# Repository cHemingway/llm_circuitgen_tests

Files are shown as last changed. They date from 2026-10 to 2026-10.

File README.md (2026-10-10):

# llm_circuitgen_tests

A benchmark of "circuit as code" tools for LLM-aided circuit design. Every tool
gets the same design brief, and each implementation lives in its own top-level
folder.

## Brief

This repository is a benchmark of various "circuit as code" tools for LLM-aided
circuit design. Each tool is given the same prompt, with the tool name and branch
substituted where needed:

> Use `<tool>` to design me a RP2354A powered Solartron 7075 multimeter
> interface, using the 50 way D connector on the Solartron. Put it in the folder
> `<tool>`. Do these changes on a new branch.
>
> DO NOT LOOK AT OTHER BRANCHES FOR CODE, RELY ON THE TOOL, THE DATASHEET, AND
> WHAT YOU CAN FIND ONLINE ONLY, DON'T COPY THE OUTPUTS OF OTHER TOOLS USED IN
> THIS BENCHMARK.
>
> In the top level folder `inputs` is a datasheet for the multimeter. It
> describes how the interface works in section 9.
>
> Signals to/from the multimeter should be opto-isolated to prevent USB ground
> noise from affecting the system. I was thinking therefore they should be done
> through shift registers to minimise the number of signals across the isolation
> barrier.
>
> Select parts from `<tool>`'s library, then LCSC where possible.
>
> Have the board sit flat on the back of the multimeter, using a vertical PCB
> mount D-Sub connector on one side and a vertical USB-B connector on the other
> side of the board.
>
> The board will be rectangular, and mechanically fixed to the solartron using
> the jackscrews on the D-Sub connector, so doesn't need any other mounting
> holes.

## Results

| Tool | Folder | Active time | of which tool time | Total tokens | API calls | API-price estimate | Schematic | PCB prints | Notes |
| --- | --- | --- | --- | --- | --- | --- | --- | --- | --- |
| [tscircuit](https://tscircuit.com) | `tscircuit/` | 3 h 11 min | 2 h 06 min | 156.3 M | 376 | $59.32 | [PDF](tscircuit/outputs/schematic.pdf) | [PDF](tscircuit/outputs/pcb-prints.pdf) | Parts from tscircuit/common, then LCSC. Session log and statistics: [`tscircuit/CONVERSATION.md`](tscircuit/CONVERSATION.md) |
| [atopile](https://atopile.io) | `atopile/` | 1 h 46 min | 38 min | 149.5 M | 370 | $49.34 | [PDF](atopile/schematic/solartron_7075_usb.pdf) | [PDF](atopile/fab/solartron_7075_usb_prints.pdf) | CLI version (`ato`, 0.15.x). This is the last open CLI line and is effectively end-of-life: [PyPI](https://pypi.org/project/atopile/) lists 0.15.9 (12 Sep 2026) as the latest release, and atopile has moved on to [0.16](https://atopile.io/enterprise). Parts from atopile's library, then LCSC. Session log and statistics: [`atopile/CONVERSATION.md`](atopile/CONVERSATION.md) |
| [SKiDL](https://github.com/devbisme/skidl) | `skidl/` | 2 h 29 min | 59 min | 124.5 M | 347 | $46.64 | [PDF](skidl/pcb/render/schematic.pdf) | [PDF](skidl/pcb/print/pcb_prints.pdf) | SKiDL 2.3.0 on KiCad 10 (the brief added "use KiCad 10"). SKiDL has no part library of its own, so parts come from KiCad's libraries, then LCSC. Board built with kinet2pcb and routed with Freerouting 2.5. SKiDL's schematic generator mis-connects nets on this design, so the schematic is drawn by a script and checked against the netlist. Statistics run to the conversation export, and exclude the merge into `main` that came after it. Session log and statistics: [`skidl/CONVERSATION.md`](skidl/CONVERSATION.md) |
| [Manta](https://github.com/Derrick-Derrickson/Manta) | `manta/` | 46 min | – | 62.9 M | 191 | – | [HTML](manta/output/solartron7075.html) | – | Manta 2.0.1 (language revision 2.0). Manta is a schematic and netlist language with no layout, so the result is a checked netlist, a KiCad netlist (with a footprint map and two generated footprints), an LCSC BOM and an HTML schematic. No PCB was made, so there are no prints. Manta's only part library is its `blinky` example; 8 part types came from it, the rest from LCSC. The session transcript kept no cost-state record, so tool time and the price estimate were not recorded; tokens and API calls are summed from the transcript's per-response usage. Statistics run to the conversation export, and exclude the merge into `main` that came after it. Notes on the tool: [`manta/README.md`](manta/README.md#notes-on-the-tool-benchmark-observations). Session log and statistics: [`manta/CONVERSATION.md`](manta/CONVERSATION.md) |

Statistics cover the Claude Code session from the first prompt to the merge into
`main`.

- **Active time:** Claude working, including tool runs such as autorouting. It
  excludes time spent waiting for the user.
- **Of which tool time:** the part of the active time spent running tools
  (builds, exports, autorouting, searches) rather than in model calls.
- **Total tokens:** these include prompt-cache reads, which dominate the total
  because every API call re-sends the conversation.
- **API-price estimate:** Claude Code's estimate at API list prices, not a bill.

A dash means the figure was not recorded.

## Breakdown

The Results figures for each tool, split by the kind of work. Every API call in
the session is put in one category according to what it was doing:

- **Schematic & research:** reading the manual, choosing parts and looking them
  up, datasheets and tool documentation, writing the circuit, and netlist and
  schematic work.
- **PCB:** footprints, placement, routing, DRC and other board checks, Gerbers,
  fabrication fixes and PCB prints.
- **Other:** commits, pushes, README writing, status checks and final
  summaries.
- **Not attributable:** calls the session's counters include but the transcript
  doesn't log, such as the `/compact` summary.

How the figures are measured:

- **Tokens:** summed from each call's logged usage.
- **Active time:** each call is credited with the time until the next call,
  including the tool runs it started.
- **API-price estimate:** per-token prices fitted to the session's cost counter
  are applied to each category's tokens.

Calls that did both kinds of work are assigned by their main purpose.

### tscircuit

| | Schematic & research | PCB | Other | Not attributable | Total |
| --- | --- | --- | --- | --- | --- |
| Active time | 1 h 08 min | 1 h 57 min | 4 min | 1 min | 3 h 11 min |
| API calls | 171 | 174 | 31 | – | 376 |
| Total tokens | 61.6 M | 75.2 M | 16.0 M | 3.5 M | 156.3 M |
| Tokens excl. cache reads | 1.33 M | 0.57 M | 0.74 M | 0.74 M | 3.38 M |
| Output tokens | 169 k | 178 k | 26 k | 9 k | 382 k |
| API-price estimate | $24.69 | $21.64 | $9.32 | $3.67 | $59.32 |

### atopile

| | Schematic & research | PCB | Other | Not attributable | Total |
| --- | --- | --- | --- | --- | --- |
| Active time | 1 h 06 min | 31 min | 9 min | 0 min | 1 h 46 min |
| API calls | 226 | 87 | 57 | – | 370 |
| Total tokens | 78.2 M | 42.0 M | 24.7 M | 4.6 M | 149.5 M |
| Tokens excl. cache reads | 0.75 M | 0.32 M | 0.80 M | 0.09 M | 1.97 M |
| Output tokens | 217 k | 104 k | 42 k | 16 k | 378 k |
| API-price estimate | $24.10 | $12.17 | $11.70 | $1.37 | $49.34 |

### SKiDL

| | Schematic & research | PCB | Other | Not attributable | Total |
| --- | --- | --- | --- | --- | --- |
| Active time | 1 h 06 min | 1 h 17 min | 5 min | 1 min | 2 h 29 min |
| API calls | 165 | 158 | 24 | – | 347 |
| Total tokens | 53.3 M | 61.0 M | 9.0 M | 1.1 M | 124.5 M |
| Tokens excl. cache reads | 0.74 M | 0.62 M | 0.69 M | 0.01 M | 2.07 M |
| Output tokens | 238 k | 196 k | 27 k | 9 k | 470 k |
| API-price estimate | $19.31 | $19.39 | $7.51 | $0.43 | $46.64 |

## Review feedback

After the design is finished, each tool's session gets the same review comments,
in this order:

> 1. Can you tidy up the routing through pin swapping the shift registers /
>    resistor arrays?
> 2. Did you try swapping pins between parts as well or just within the same
>    part?
> 3. Try moving parts too

Statistics are measured as above, from the first review comment to the last
reply.

| Tool | Active time | of which tool time | Total tokens | API calls | API-price estimate | Notes |
| --- | --- | --- | --- | --- | --- | --- |
| [tscircuit](https://tscircuit.com) | 1 h 35 min | 1 h 12 min | 48.9 M | 97 | $16.38 | Review log and statistics: [`tscircuit/REVIEW_CONVERSATION.md`](tscircuit/REVIEW_CONVERSATION.md) |
| [atopile](https://atopile.io) | 2 h 28 min | 2 h 03 min | 53.1 M | 141 | $16.94 | Review log and statistics: [`atopile/REVIEW_CONVERSATION.md`](atopile/REVIEW_CONVERSATION.md) |
| [SKiDL](https://github.com/devbisme/skidl) | – | – | – | – | – | |
| [Manta](https://github.com/Derrick-Derrickson/Manta) | – | – | – | – | – | |

## Layout

| Folder | Contents |
| --- | --- |
| `inputs/` | Source material: OCR'd Solartron 7075 service manual (interface in Section 9) |
| `tscircuit/` | [tscircuit](https://tscircuit.com) implementation; see its README |
| `atopile/` | [atopile](https://atopile.io) (CLI) implementation; see its README |
| `skidl/` | [SKiDL](https://github.com/devbisme/skidl) implementation, with a KiCad 10 board; see its README |
| `manta/` | [Manta](https://github.com/Derrick-Derrickson/Manta) implementation, schematic and netlist only (no board); see its README |

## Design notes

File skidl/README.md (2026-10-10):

# Solartron 7075 → USB interface (SKiDL)

An isolated USB interface for the Solartron 7075 DVM, described in
[SKiDL](https://github.com/devbisme/skidl) and laid out for KiCad 10. It plugs
into the 50-way Cannon socket (**SKB**) of the 7075's Parallel BCD Interface
Unit 70754 (service manual section 9). From there it reads the display data and
status lines, drives all the remote-control inputs, and connects to a host over
USB through an RP2354A.

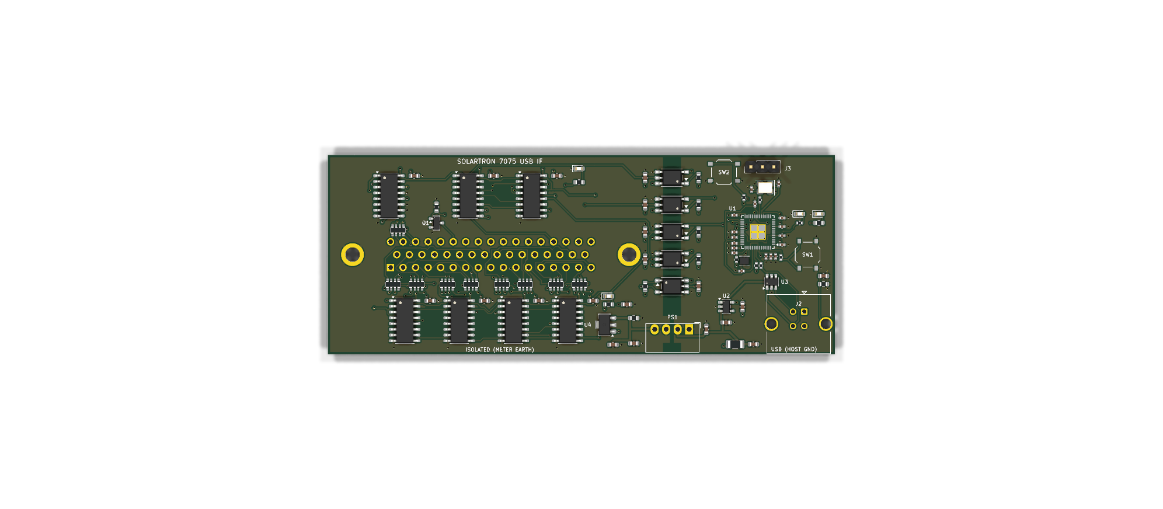
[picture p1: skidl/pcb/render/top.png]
top


| | |
|---|---|
| Board | 112 × 44 mm, 4 layers, 1.6 mm, rectangular, no mounting holes |
| Meter connector | J1, DD-50 **male** (plug), vertical, mounted on the **bottom** side. Two 4-40 jackscrews through its flange holes hold the board on the instrument |
| Host connector | J2, USB-B **vertical** (TE 5787834-1), mounted on the **top** side at the other end of the board |
| MCU | RP2354A (RP2350 with 2 MB of flash in the package), 12 MHz crystal, SWD header, BOOTSEL and RESET buttons |
| Isolation | 5 × TLP2361 optocouplers (4 to the meter, 1 back) + B0509S isolated DC/DC. There is a 4 mm copper-free gap between the domains (0.8 mm at the DC/DC pins) |
| Meter side | 5 × 74HCT165 (36 inputs + 4 check bits), 2 × 74HC595 (13 command outputs), supplied from its own regulated 5 V |
| Checks | SKiDL ERC: 0 errors / 0 warnings. Schematic ERC (KiCad 10, all severities): 0 violations (`pcb/erc_report.txt`). DRC with schematic parity (all severities): **0 violations, 0 unconnected, 0 parity errors** (`pcb/drc_report.txt`) |

## Schematic

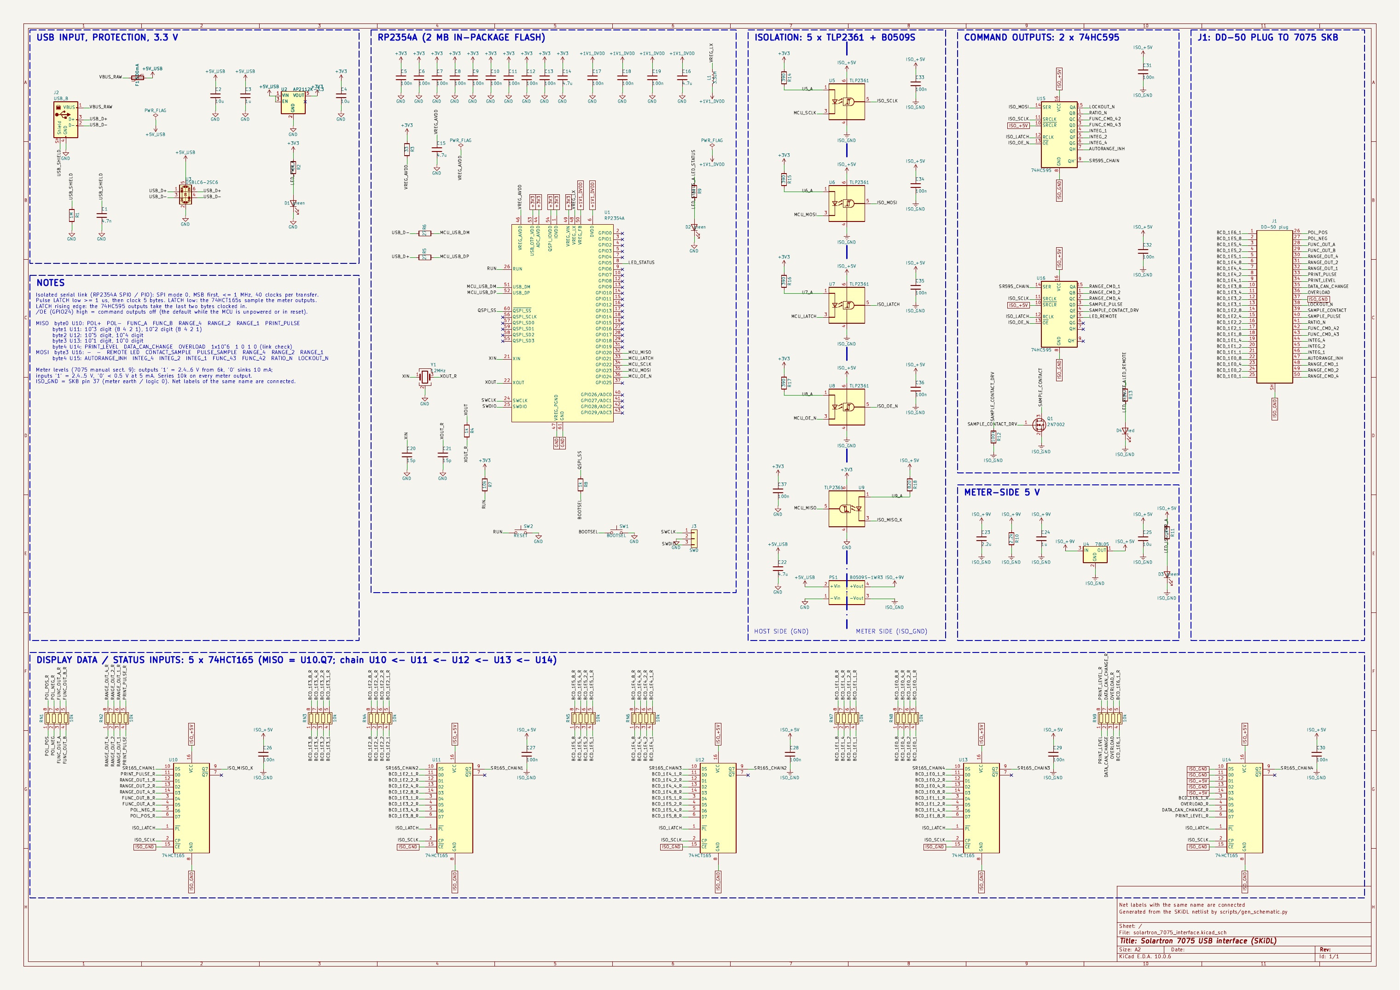
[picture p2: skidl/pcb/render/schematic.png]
schematic


One A2 sheet (`pcb/solartron_7075_interface.kicad_sch`, PDF in
`pcb/render/schematic.pdf`), grouped by function: USB input and 3.3 V, the
RP2354A, the isolation barrier (drawn as a dashed line through the
optocouplers and the DC/DC), the 595 command outputs, the meter-side 5 V, J1,
and the 165 input chain along the bottom. Labels with the same name are
connected.

SKiDL's own schematic output is not usable on this design (see
[Tool issues](#tool-issues)), so `scripts/gen_schematic.py` draws the sheet from
the SKiDL netlist. Part positions are set by hand per block; every pin then
gets a stub with a net label, power symbol or no-connect flag. The script
re-exports the netlist from the drawn sheet with `kicad-cli` and fails unless
every net has the same pins and the same name as in the SKiDL netlist.
`scripts/link_schematic.py` then ties the board's footprints to the symbols,
so KiCad's schematic-parity DRC and cross-probing work.

## How it works

```mermaid
flowchart LR
  subgraph USB["USB / host side (GND)"]
    J2[USB-B vertical] --> F1[500 mA PTC] --> ESD[USBLC6] --> LDO[AP2112K 3.3 V]
    LDO --> MCU[RP2354A]
    J2 -- D+/D- 27R --> MCU
  end
  subgraph ISO["Meter side (ISO_GND = 7075 pin 37 earth)"]
    REG[78L05] --> SR165[5 × 74HCT165]
    REG --> SR595[2 × 74HC595]
    SR595 --> Q1[2N7002 contact sample]
    SR165 --- RN[9 × 4 × 10k series]
  end
  MCU -- "SCLK, MOSI, LATCH, /OE (4 × TLP2361)" --> SR165 & SR595
  SR165 -- "MISO (1 × TLP2361)" --> MCU
  LDO -. "+5 V" .-> DCDC[B0509S 1 W isolated] -. "9 V" .-> REG
  RN --- J1[DD-50 plug to SKB]
  SR595 --- J1
  Q1 --- J1
```

* **Five signals cross the barrier.** SCLK, MOSI, LATCH and /OE go to the
  meter, and MISO comes back. Every meter output is captured by the 165 chain,
  and every meter input is driven by the 595 chain.
* **One LATCH line serves both chains.** LATCH low makes the 74HCT165s load
  (snapshot) the meter outputs. The rising edge of LATCH copies the 74HC595
  shift registers to their outputs.
* **The command outputs are safe at power-up.** The /OE optocoupler output sits
  high whenever its LED is off (MCU unpowered, in reset, or not yet
  initialised), so the 595 outputs stay high-impedance. The meter's TTL inputs
  then float to '1', which is the "nothing commanded" state. The manual notes
  that an unconnected interface leaves the meter in 10 s / DC V. The
  CONTACT-SAMPLE MOSFET has a 100 k gate pull-down for the same reason.
* **Logic levels follow the section-9 spec.**
  * Meter outputs are '1' = 2.4…6 V from a 6 kΩ source, so the 165s are
    **HCT** parts with TTL thresholds (V<sub>IH</sub> 2.0 V).
  * Each meter output passes through a 10 kΩ series resistor in a 4-way array.
    This limits ESD current and back-feeding when only one side is powered.
  * Meter inputs need '0' < 0.5 V at 5 mA sink and '1' < +5 V. The 74HC595
    meets both on a regulated 5 V.
  * That is why the meter side uses B0509S → 78L05 rather than an unregulated
    5 V → 5 V module. Such a module only holds 5 V above about 10 % load
    (20 mA), and this board draws about 15 mA, so its output would drift
    above the meter's input limit.
* **CONTACT SAMPLE** (pin 39) wants a real closure to pin 37, so it gets a
  2N7002. **PULSE SAMPLE** (pin 40) is driven directly (+5 V, keep it high for
  more than 100 µs).
* **Optocouplers.** The TLP2361 is a 15 MBd part with a totem-pole output and a
  threshold of ≤ 1.6 mA, so logic can drive its LED directly.
  * MCU side: 390 Ω from 3.3 V gives ≈ 3.6 mA.
  * Meter side: 820 Ω from 5 V gives ≈ 3.9 mA.
  * The LED cathode is pulled low by the driving logic, so each channel is
    non-inverting overall.

### RP2354A pin use

| GPIO | Pin | Function |
|---|---|---|
| GPIO20 | 32 | MISO (SPI0 RX) ← U9 |
| GPIO21 | 33 | LATCH → U7 |
| GPIO22 | 34 | SCLK (SPI0 SCK) → U5 |
| GPIO23 | 35 | MOSI (SPI0 TX) → U6 |
| GPIO24 | 36 | /OE of the 595s → U8 (drive low only after the first valid transfer) |
| GPIO5 | 8 | status LED D2 (active high) |
| SWCLK/SWDIO | 24/25 | J3 (SWCLK, GND, SWDIO) |
| QSPI_SS | 60 | BOOTSEL button SW1 (1 k) |
| RUN | 26 | RESET button SW2, 10 k pull-up |

GPIO20–24 are contiguous, so a single PIO program can drive them as well as
hardware SPI0. The QSPI pins are unconnected because the flash is inside the
RP2354A package.

## Transfer protocol and bit maps

Each transfer is 40 clocks: SPI mode 0, MSB first, SCLK ≤ 1 MHz recommended.
The optocouplers add about 0.2 µs round trip, which leaves plenty of margin
up to about 2 MHz.

1. Pulse LATCH low for ≥ 1 µs, then return it high. The pulse snapshots the
   meter outputs into the 165s. Its rising edge applies the command bytes sent
   in the previous transfer.
2. Clock 5 bytes. Read bytes 0–4 from MISO and send the command bytes on MOSI.
   Only the last two bytes sent stay in the 595 chain.
3. To apply new commands immediately, pulse LATCH again.

**MISO, bytes 0–4 (MSB first):**

| Byte | Register | bit7 … bit0 |
|---|---|---|
| 0 | U10 | POL+ (26), POL− (27), FUNC A (28), FUNC B (29), RANGE 4 (30), RANGE 2 (31), RANGE 1 (32), PRINT PULSE (33) |
| 1 | U11 | 10³ digit 8 4 2 1 (pins 10–13), 10² digit 8 4 2 1 (14–17) |
| 2 | U12 | 10⁵ digit (2–5), 10⁴ digit (6–9) |
| 3 | U13 | 10¹ digit (18–21), 10⁰ digit (22–25) |
| 4 | U14 | PRINT LEVEL (34), DATA CAN CHANGE (35), OVERLOAD (36), 1 × 10⁶ (1), **1 0 1 0** |

The low nibble of byte 4 is wired to a fixed `1010` pattern on the meter side.
If it reads back as anything else, the link is broken or the isolated side is
unpowered: an unpowered side reads as all ones.

**MOSI, bytes 3 and 4 (the last two sent):**

| Byte | Register | bit7 (QH) … bit0 (QA) |
|---|---|---|
| 3 | U16 | –, –, REMOTE LED D4, CONTACT SAMPLE (39, via Q1, 1 = close), PULSE SAMPLE (40), RANGE 4 (50), RANGE 2 (49), RANGE 1 (48) |
| 4 | U15 | AUTORANGE inhibit (47), INTEG 4 (44), INTEG 2 (45), INTEG 1 (46), FUNC (43), FUNC (42), RATIO (41, 0 = ratio), FRONT PANEL LOCKOUT (38, 0 = lockout/remote) |

Bytes 0–2 on MOSI are don't-care: they fall out of the end of the 595 chain.

Typical remote measurement:

1. Write the function, range and integration codes from the manual's tables,
   with LOCKOUT = 0.
2. Set PULSE SAMPLE = 1, wait ≥ 100 µs, then set it back to 0. Each change
   is one transfer plus a LATCH pulse.
3. Poll until PRINT LEVEL = 1.
4. Read the BCD digits, polarity, range and function codes from the same
   snapshot.

## Connector pin map (J1 ↔ 70754 SKB)

| SKB pin | Signal | Board net | SKB pin | Signal | Board net |
|---|---|---|---|---|---|
| 1 | 1 × 10⁶ | BCD_1E6_1 | 26 / 27 | +ve / −ve polarity | POL_POS / POL_NEG |
| 2–5 | 8,4,2,1 × 10⁵ | BCD_1E5_* | 28 / 29 | function out | FUNC_OUT_A / B |
| 6–9 | × 10⁴ | BCD_1E4_* | 30 / 31 / 32 | range out (4/2/1) | RANGE_OUT_* |
| 10–13 | × 10³ | BCD_1E3_* | 33 / 34 | print pulse / level | PRINT_PULSE / PRINT_LEVEL |
| 14–17 | × 10² | BCD_1E2_* | 35 / 36 | data can change / overload | DATA_CAN_CHANGE / OVERLOAD |
| 18–21 | × 10¹ | BCD_1E1_* | 37 | earth / logic 0 | **ISO_GND** (+ J1 shell) |
| 22–25 | × 10⁰ | BCD_1E0_* | 38–50 | command inputs | see MOSI map |

## Mechanical notes

* **J1 is on the underside**, centred at (36, 22) mm in the KiCad top view.
  * Its pins 1–17 (the wide row of the D) face the board's lower edge, the edge
    with the "ISOLATED (METER EARTH)" legend.
  * The jackscrew holes are Ø 3.2 mm at (5.445, 22) and (66.555, 22), 61.11 mm
    apart (DD-50 standard).
  * Fit two 4-40 UNC jackscrews or thumbscrews from the top through the board
    and the connector flange into the socket's screw-locks. Thread length should
    be ≥ 10 mm (1.6 mm board + flange + engagement).
  * No other parts sit on the underside. Keep at least 3 mm of clearance around
    the screw heads on top, which the layout already does.
* The board stands off the instrument by roughly the connector's body height,
  about 12 mm for the Amphenol Delta-D straight series. Check this against the
  part you buy.
* Relative to the socket, the board extends 36 mm on the J1 side and 76 mm on
  the USB side. If something on your unit is in the way on that side, J1's
  orientation can be changed in `scripts/layout_pcb.py` (`j1_ok`). Everything
  else then needs re-placing.
* The vertical USB-B on the top face points away from the instrument.

## Parts and sourcing

* Every part has an LCSC code. The grouped BOM with MPNs is in
  `output/bom.csv`, and the JLCPCB-format BOM and CPL are in `pcb/fab/`.
* Symbols and footprints come from the stock KiCad 10 libraries, except:
  * **J1:** KiCad 10 has no 50-way D-sub. `scripts/gen_dd50_footprint.py` and
    `scripts/gen_symbols.py` generate `lib/Solartron7075.*` from the Amphenol
    Delta-D drawing.
  * **TLP2361:** there is no KiCad symbol, so the identically-pinned
    `Isolator:TLP2310` symbol is used (SO6 with 5 leads: A 1, K 3, GND 4, VO 5,
    VCC 6). The footprint is `Toshiba_SOIC-5-6`.
  * **B0509S-1WR3:** uses the Murata MEE1 symbol and footprint, which have the
    same SIP-4 pinout.
* **J1 (Amphenol D50P24A4PA00LF, C17502305)** was listed on LCSC without stock
  at design time. Any straight-PCB DD-50 plug with plain 3.1 mm flange holes on
  the standard 2.77 × 2.84 mm grid fits. Don't use one with female screw-locks.
* The jackscrews are not on LCSC.
* Power budget is under 120 mA from USB:
  * RP2354A: ~30 mA
  * Opto LEDs: ≤ 15 mA
  * LEDs: ~5 mA
  * Isolated side: ≈ 15 mA at 5 V, ≈ 40 mA at the DC/DC input
* Isolation is **functional**: its purpose is to break the USB/earth ground loop
  and keep USB noise away from the meter. It is not a safety barrier. The
  TLP2361s are rated 3.75 kV<sub>rms</sub> and the B0509S 1.5 kV DC.

## Gerbers and prints

| File | Contents |
|---|---|
| `pcb/fab/gerbers.zip` | Gerbers for 4 layers, mask, paste, silkscreen and outline, plus Excellon drill files (PTH; the NPTH file is empty) and drill maps. Upload this to the board house |
| `pcb/fab/bom_jlcpcb.csv`, `pcb/fab/cpl_jlcpcb.csv` | JLCPCB assembly BOM and placement |
| `pcb/print/pcb_prints.pdf` | 7 A4 pages, black and white, with title block: top and bottom assembly (fab layers, pads sketched), F.Cu, In1.Cu, In2.Cu and B.Cu, all at 2:1, then a 1:1 bottom view for a fit check |
| `pcb/print/gerber_preview.png` | the Gerber and drill files rendered by gerbv, independently of KiCad |
| `pcb/render/` | KiCad 3D renders and a colour multi-layer PDF |

For the fit check, print page 7 at 100 % ("actual size"). The board outline
there should measure 112 × 44 mm. Hold it against the meter's SKB socket to
check the jackscrew holes, the pin rows and the overhang on each side. Bottom
views (pages 2, 6 and 7) are mirrored, so they show the board as seen from
the meter side.

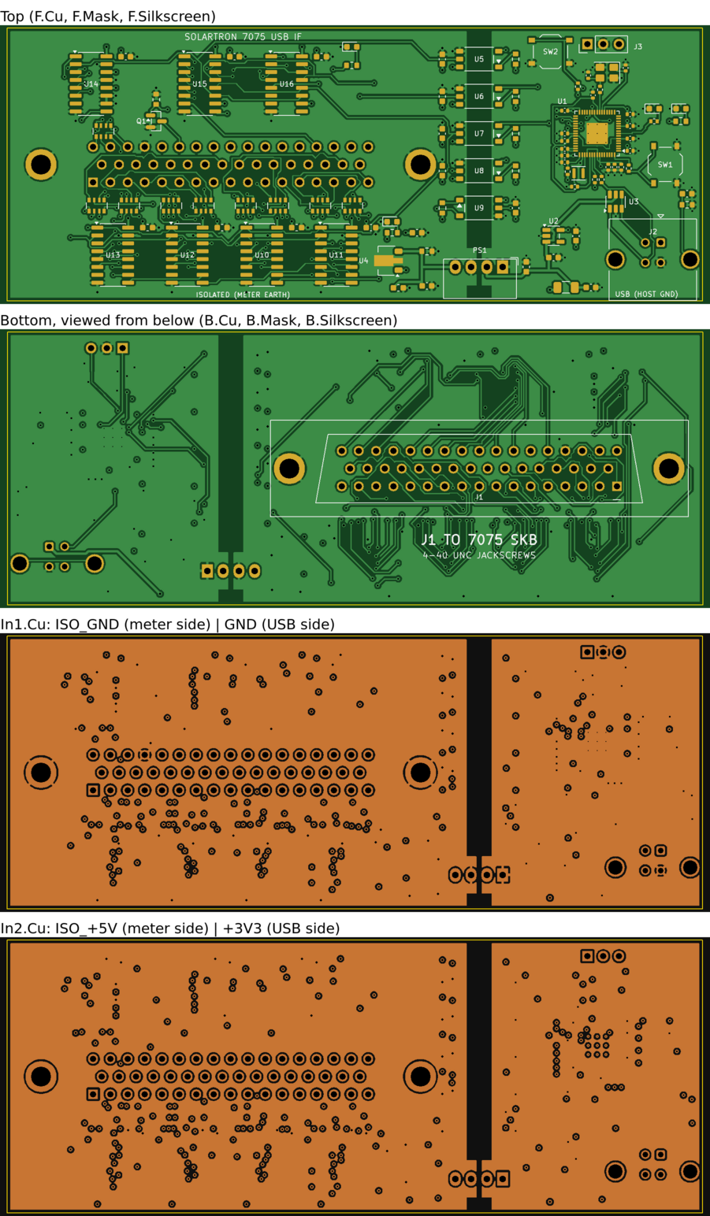
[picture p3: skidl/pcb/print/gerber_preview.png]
Gerber preview


## Files

| Path | What |
|---|---|
| `solartron_7075_interface.py` | the SKiDL design (all parts, nets, LCSC/MPN fields) |
| `lib/` | generated DD-50 symbol + footprint |
| `scripts/gen_dd50_footprint.py`, `scripts/gen_symbols.py` | library generators |
| `scripts/layout_pcb.py` | placement, stack-up, rules, planes, isolation keep-outs, silkscreen |
| `scripts/route_pcb.py`, `scripts/fanout.py` | QFN hand fan-out, plane vias, Freerouting, clean-up, ground pours |
| `scripts/gen_schematic.py` | draws the single-page schematic from the netlist and checks it (`--check`) |
| `scripts/link_schematic.py` | links the routed board to the schematic (symbol paths, net names) |
| `scripts/make_bom.py`, `scripts/jlc_cpl.py` | BOM and placement files |
| `scripts/make_prints.py` | the print PDF and the Gerber preview |
| `build.sh` | runs the whole flow |
| `CONVERSATION.md` | export of the Claude Code session that produced this design, with its time and token totals |
| `scripts/session_breakdown.py`, `stats/breakdown_calls.csv` | the split of the session statistics by kind of work, and the category of every API call |
| `output/` | SKiDL netlist, ERC log, BOM, unplaced board straight from SKiDL |
| `pcb/` | KiCad 10 project: schematic, routed board, ERC and DRC reports, `render/` (schematic PDF/PNG, board renders), `print/` (prints, Gerber preview), `fab/` (Gerbers, drill, BOM, CPL) |

## Rebuilding

Tested with KiCad 10.0.6 (Ubuntu PPA), SKiDL 2.3.0 with kinet2pcb 1.1.4,
Freerouting 2.5.0 (needs Java 25), and Python 3.12. Use the system Python,
because it has KiCad's `pcbnew` module. The prints need `pdfunite` and
`pdftoppm` (poppler-utils) and ImageMagick. `gerbv` is optional; without it the
Gerber preview is skipped.

```sh
python3 -m venv --system-site-packages .venv && .venv/bin/pip install skidl
SKIDL_PYTHON=.venv/bin/python FREEROUTING_JAR=/path/freerouting-2.5.0-executable.jar \
JAVA=/usr/lib/jvm/java-25-openjdk-amd64/bin/java ./build.sh
```

The full run takes about 8 minutes, mostly in Freerouting's optimiser.
Freerouting is not fully deterministic, so a rebuild gives a board that is
equivalent but not byte-identical. The committed board is the one checked by
`pcb/drc_report.txt`.

## Session statistics breakdown

The root README's Breakdown table for SKiDL comes from
`scripts/session_breakdown.py`, which reads the session's Claude Code
transcript. The category of each of the 347 API calls is listed in
`stats/breakdown_calls.csv`. Notes on the method:

* **Span.** The span runs from the first prompt to the request to export the
  conversation, the same as the Results row. This session has not had the
  review comments yet.
* **Categories.** Calls are assigned by hand, from index ranges in the script.
  The less obvious calls:
  * Installing KiCad and SKiDL counts as tool research. Freerouting, Java and
    the 3D models count as PCB.
  * Checking which footprints fit the chosen parts counts as PCB, and so does
    the DD-50 footprint.
  * The BOM and the later LED and passive swaps count as part selection.
  * Linking the board to the schematic (`link_schematic.py`, the parity DRC)
    counts as PCB.
* **Cache rewrite.** "Other" includes a 0.62 M-token prompt-cache write
  (about $5). The first call after the 6 h pause at the usage limit had to
  re-cache the whole conversation, and that call was a `git status` check.
* **Not attributable.** This column holds the automatic compaction (77 s) and
  1.13 M tokens that the cost counter includes but the transcript does not log
  per call.
* **Prices.** The fitted prices are $4.41 per million input tokens, $8.00 for
  cache writes, $0.200 for cache reads and $20.03 for output.
  * They reproduce all four of the session's cost snapshots to within 1e-13
    dollars.
  * Four snapshots and four prices make the fit exact. So it is checked only
    by the other three prices coming out as round figures.
  * The input price is poorly determined, because there are only 5 k uncached
    input tokens. Its effect on any column is under $0.02.

## Tool issues

Problems with SKiDL, kinet2pcb, Freerouting and the KiCad libraries, and what
this flow does about them.

* **SKiDL schematic generator.** SKiDL 2.3's KiCad 10 schematic output
  (`SKIDL_SCH=1`, hierarchical or flat) runs, but on this design it draws some
  power symbols and labels touching other nets. KiCad's netlist export of the
  result merges nets, e.g. +3V3 with +1V1_DVDD, and puts decoupling caps on the
  wrong rails. It is off by default. The shipped sheet comes from
  `scripts/gen_schematic.py` and is checked against the netlist, as described
  under [Schematic](#schematic).
* **kinet2pcb:**
  * It can't parse KiCad 10's quoted `fp-lib-table` entries, so the footprint
    directories are passed explicitly.
  * It puts every no-connect pin on one shared `__NOCONNECT` net, so
    `layout_pcb.py` detaches them.
  * Its footprints carry no symbol paths, so the board is not linked to any
    schematic. `link_schematic.py` adds the paths and BOM fields, renames nets
    the way KiCad's "Update PCB from Schematic" would (local-label nets become
    `/NAME`), and gives no-connect pins their `unconnected-(…)` nets.
* **SKiDL pin names.** SKiDL mangles pin names containing `'` (the 595's
  `QH'`), so pin numbers are used there.
* **Freerouting** doesn't drop vias into the inner planes by itself, and it
  can't escape the RP2354A's 0.4 mm-pitch supply pins. The QFN fan-out and the
  plane vias are pre-routed and locked, and Freerouting routes the rest. It is
  also not fully deterministic (see [Rebuilding](#rebuilding)).
* **KiCad libraries.** There is no 50-way D-sub footprint or TLP2361 symbol,
  so these are generated or substituted (see
  [Parts and sourcing](#parts-and-sourcing)). The 3D library has no models for
  the DD-50, the vertical USB-B, the TS-1187A switches, the MEE1/B0509S or the
  QFN-60, so those parts are missing from the renders.

## Design caveats

* **Not built or bench-tested.** Before ordering:
  * Check J1's footprint against the datasheet of the plug you actually buy.
  * Check the jackscrew thread and the socket orientation on your 70754.
  * Check the orientation of every part in JLCPCB's placement preview.
* **Power sequencing.** If the meter is switched off while the board is powered
  and /OE is enabled, the 595 outputs back-feed the meter's TTL inputs.
  Firmware should release /OE when the meter outputs read implausibly, for
  example everything low.
* The 595s' '1' level is the 78L05 output, 5.0 V ± 4 %. The manual gives
  "< +5 V" for its inputs, which the TTL inputs tolerate.
* J1 had no LCSC stock at design time, and the jackscrews are not on LCSC (see
  [Parts and sourcing](#parts-and-sourcing)).
* Isolation is functional, not a safety barrier.
* No firmware is included.

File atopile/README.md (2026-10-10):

# Solartron 7075 USB interface (atopile)

An RP2354A USB interface that plugs straight into the 50-way SKB socket of a
Solartron 7075 DVM fitted with the 70754 Parallel BCD Interface Unit (service
manual, section 9). Every signal to and from the meter crosses an optical
isolation barrier, so USB ground noise never reaches the meter's ground. SKB
pin 37 is the meter's earth and logic 0.

Designed with atopile 0.15.9 (`ato build`). The parts come from atopile's
package library where it had them, and from LCSC otherwise.

## Architecture

```
 USB side (GND)                         |  DVM side (GND_ISO)
                                        |
 USB-B (vertical) -> 500 mA PTC, USBLC6 |
   +5V --+--> TLV75901 -> +3V3          |
         +--> IB0505LS-1WR3 ===========>|==> +5V_ISO (regulated, 1.5 kV)
                                        |
 RP2354A  GPIO18 SCK  --> TLP2361 ======|==> SCK_ISO   -> 5x 74HCT165 CP, 2x 74HCT595 SHCP
          GPIO19 MOSI --> TLP2361 ======|==> MOSI_ISO  -> first 74HCT595 DS
          GPIO17 LATCH--> TLP2361 ======|==> LATCH_ISO -> 74HCT165 /PL, 74HCT595 STCP
          GPIO20 OE_N --> TLP2361 ======|==> OE_N_ISO  -> 74HCT595 /OE (10 k pull-up)
          GPIO16 MISO <-- TLP2361 ======|<== first 74HCT165 Q7
          GPIO21 DRDY <-- TLP2361 ======|<== 74AHCT1G125 <- SKB 34 (PRINT level)
                                        |
                                        |   SKB 1-36  (BCD, polarity, function, range,
                                        |              print, data-can-change, overload)
                                        |              -> 5x 74HCT165 (40-bit chain)
                                        |   SKB 38, 40-50 <- 2x 74HCT595 (16-bit chain)
                                        |   SKB 39 (contact SAMPLE) <- 2N7002 to pin 37
```

* Only six logic signals cross the barrier. Each goes through a Toshiba
  TLP2361 optocoupler (15 MBd, 80 ns max delay). Every channel is
  non-inverting: the MCU or HCT output sinks the LED cathode, and the anode
  is fed from 330 Ω (3.3 V side) or 680 Ω (5 V side), about 4.5 mA.
* The DVM side uses HCT logic at 5 V because the 7075's outputs are TTL
  levels: a '1' is +2.4 to +6 V from a 6 kΩ source. The 74HCT595 outputs
  sink 6 mA at under 0.33 V, which meets the 7075 input spec of under 0.5 V
  at 5 mA.
* **Safe at reset.** While the MCU is in reset or not yet configured, its
  GPIOs are Hi-Z, so the opto LEDs are off and every isolated line idles
  high. That keeps `OE_N_ISO` high, so the 595 outputs stay Hi-Z and the
  meter's command inputs sit at its own pull-ups, exactly as if nothing were
  connected. Manual §9, diagram 9.2 (70754 board 2) confirms the pull-ups:
  * every command input has 4.7 kΩ to +5 V into 74-series TTL, so Hi-Z reads
    '1' = inactive (no lockout, no ratio, DC, 10 s, autorange; the manual's
    "REMOTE with nothing connected" state)
  * CONTACT SAMPLE has 2.2 kΩ to +5 V, so with the MOSFET off there is no
    sample
  * PULSE SAMPLE is AC-coupled (47 kΩ + 22 nF), so only a rising edge
    triggers it
* The four spare 74HCT165 inputs are tied to two 1s and two 0s, so firmware
  can detect a broken link or a missing isolated supply. Their places in the
  frame are in the read-frame table below.

## Firmware interface

SPI0 runs in mode 0 at 1 MHz or less. The limit comes from the round trip
through two optos, about 200 ns. **LATCH must be driven as a plain GPIO**, not
as the SPI chip select, because the 74HCT165s are held in load mode while it
is low. Set GPIO17–20 to 8 mA drive.

One transaction:

1. Pulse LATCH (GPIO17) low for at least 1 µs, then return it high. The
   rising edge does two things: the 165s capture the DVM outputs, and the
   595s present the command word that was shifted in last time.
2. Exchange 5 bytes over SPI. MOSI = `00 00 00 CMD_HI CMD_LO`. MISO = 5
   status bytes.
3. To apply the new command now, pulse LATCH again. Otherwise it is applied
   at the next transaction.
4. After the first valid command has been latched, drive OE_N (GPIO20) low.
   That command must have the PULSE SAMPLE bit = 0. PULSE SAMPLE is
   AC-coupled in the meter, so enabling the outputs with that bit = 1 would be
   a rising edge and would trigger a sample.

DRDY (GPIO21) follows SKB pin 34, PRINT level. It goes high when a reading is
complete and the outputs have been updated.

<!-- BEGIN bit maps: generated by scripts/pin_swap.py -->
### Read frame (MISO, MSB first)

Each cell gives the SKB pin and its meaning. `1`/`0` are the link-check
constants: firmware should check them on every read.

| Byte | bit7 | bit6 | bit5 | bit4 | bit3 | bit2 | bit1 | bit0 |
|---|---|---|---|---|---|---|---|---|
| 0 | 1 1×10⁶ | 34 PRINT level | 2 8×10⁵ | 18 8×10¹ | `0` | `1` | `0` | 35 DATA CAN CHANGE |
| 1 | 19 4×10¹ | 3 4×10⁵ | 36 OVERLOAD | 20 2×10¹ | 22 8×10⁰ | 5 1×10⁵ | 21 1×10¹ | 4 2×10⁵ |
| 2 | 6 8×10⁴ | 23 4×10⁰ | 7 4×10⁴ | 24 2×10⁰ | `1` | 9 1×10⁴ | 25 1×10⁰ | 8 2×10⁴ |
| 3 | 11 4×10³ | 27 −ve | 10 8×10³ | 26 +ve | 28 function A | 12 2×10³ | 29 function B | 13 1×10³ |
| 4 | 32 range (1) | 14 8×10² | 31 range (2) | 30 range (4) | 15 4×10² | 33 PRINT pulse | 16 2×10² | 17 1×10² |

### Command word (MOSI bytes 3–4, CMD_HI = bits 15–8)

| Bit | SKB pin | Signal (manual §9) |
|---|---|---|
| 0 | 38 | FRONT PANEL LOCKOUT (0 = locked out) |
| 1 | 39 | CONTACT SAMPLE (1 = MOSFET closes 39 to 37) |
| 2 | 43 | FUNCTION B |
| 3 | 42 | FUNCTION A |
| 4 | 44 | Integration time (4) |
| 5 | 41 | RATIO (0 = ratio) |
| 6 | 40 | PULSE SAMPLE (pulse high for more than 100 µs) |
| 7 | – | unused |
| 8 | 45 | Integration time (2) |
| 9 | 49 | Range (2) |
| 10 | 50 | Range (4) |
| 11 | 48 | Range (1) |
| 12 | 47 | AUTORANGE (1 = autorange inhibited, use the commanded range) |
| 13 | 46 | Integration time (1) |
| 14 | – | unused |
| 15 | – | unused |

* FUNCTION, read as (43, 42): 11 = DC, 01 = AC, 10 = Ω, 00 = CHECK.
* Integration time, read as (44, 45, 46) = (4)(2)(1): 011 = 1 ms, 100 = 20 ms,
  101 = 100 ms, 110 = 1 s, 111 = 10 s.
* Range, read as (50, 49, 48) = (4)(2)(1): 000 = 1000 V / 10 MΩ … 101 = 10 mV /
  100 Ω, 110 = auto / 10 Ω, 111 = auto.
<!-- END bit maps -->

Commands only take effect while the meter is in REMOTE. That means either the
REMOTE button is pressed, or the FRONT PANEL LOCKOUT bit = 0.

## Board

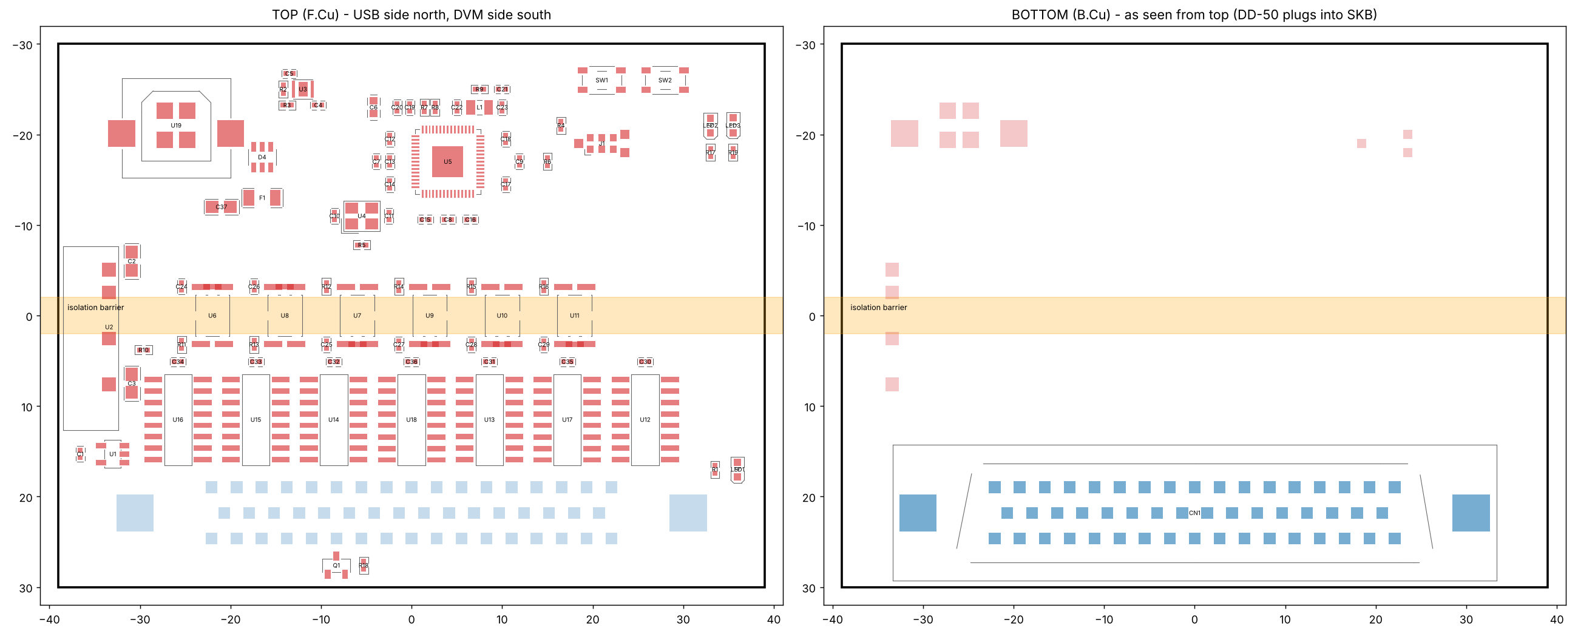
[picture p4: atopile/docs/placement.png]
placement


* 78 × 60 mm rectangle, 4 layers, 1.6 mm. It sits flat on the back of the
  meter and has no mounting holes.
* **Stack-up** (JLCPCB's standard 7628 build, nominal values):

  | Layer | Use | Copper | Dielectric below |
  |---|---|---|---|
  | F.Cu | signals, all parts except the DD-50 | 35 µm | 0.2 mm 7628 prepreg |
  | In1.Cu | ground planes: GND (USB half), GND_ISO (DVM half) | 17.5 µm | 1.065 mm core |
  | In2.Cu | supply planes: +3V3 (USB half), +5V_ISO (DVM half) | 17.5 µm | 0.2 mm 7628 prepreg |
  | B.Cu | signals, DD-50 | 35 µm | |

* **Bottom face:** Amphenol DD50P364TXLF, a vertical PCB-mount DD-50 plug. It
  mates with SKB and is held by 4-40 jackscrews through its 3.1 mm flange
  holes. The top face is kept clear within 4 mm of each jackscrew for the
  screw heads.
* **Top face:**
  * the vertical USB-B (SHOU HAN BF 180) and the rest of the components
  * isolation barrier along the board centreline: a 3.2 mm keep-out on all
    four layers with no tracks, vias or copper, crossed only by the six
    TLP2361s and the SIP DC-DC. The inner planes stop 1.9 mm either side of
    the centreline, so the planes on the two sides are 3.8 mm apart.
  * no pours on the outer layers; they are left for signals
* `scripts/place_components.py` produces the initial placement, the layer
  stack and the zones, using atopile's own `PCB_Transformer`.
  `scripts/check_layout.py` checks:
  * every pad is inside the outline
  * no footprints overlap
  * all USB-side pads are north of the barrier and all DVM-side pads south
  * the jackscrew keep-outs are clear
* The TLV75901 library module arrives pre-routed. The placement script moves
  its parts, tracks and vias as one rigid block so that routing stays valid.
* `layouts/default/default.kicad_pro` sets 0.127 mm track/space, 0.3 mm
  drill and a 0.25 mm default track, all within JLCPCB's 4-layer minimums.
* **Routed**, with KiCad's DRC clean (no errors, no unrouted connections):
  see "Planes and routing" below.

### Pin swapping and part moves

DVM-side ratsnest: original, after pin swapping, after moving parts

Blue: SKB outputs to 74HCT165 inputs. Orange: 74HCT595 outputs to SKB
command inputs and the SAMPLE MOSFET. Green: the two shift chains. Grey:
the control nets (SCK/LATCH/OE_N/DRDY) and the MOSFET drain to SKB 39.

**Pin swapping.** `scripts/pin_swap.py` decides which SKB signal goes on
which shift-register pin. Swaps are made within a part and between parts.
* Any SKB output (pins 1–36) can go on any of the 40 74HCT165 inputs. The
  four link-check constants take the spare inputs.
* Any SKB command input (38, 40–50) and the SAMPLE MOSFET gate can go on any
  of the 16 74HCT595 outputs.
* The order of the five 165s in their chain, and of the two 595s, is free.

The script minimises ratsnest length plus 5 mm per ratsnest crossing, using
seeded simulated annealing. Crossings with the control nets count too. It
then rewrites the generated `pin map` block in `main.ato` and the bit-map
tables under "Firmware interface", so the firmware tables always match the
board.

**Moving parts.** `scripts/optimise_placement.py` then searched the DVM-side
placement, running a short pin-swap search for every candidate:
* which register type sits in each of the seven slots of the IC row, and
  the rotation of the 165s and of the 595s
* a few legal spots each for the DRDY buffer (U1) and the SAMPLE MOSFET (Q1)
* the order of the six optocouplers along the barrier

The result, written into the generated block of `place_components.py`:
* IC row, east to west: 165, 595, 165, 595, 165, 165, 165. The 595s now sit
  above SKB 38–50.
* The 165s are turned 180°, so their LATCH/SCK pins face away from the
  DD-50 and their chain pins (QH, SER) face it.
* U1 moved from the east end to the west end, next to SKB 34.
* Q1 and its pull-down moved from the east end to the strip south of the
  DD-50, in line with SKB 39.
* The opto order, west to east, is now DRDY, MISO, LATCH, MOSI, OE_N, SCK.
  That puts DRDY next to U1 and MISO next to the head of the 165 chain.

| DVM-side ratsnest | Original | Pin swap | Pin swap + moved parts |
|---|---|---|---|
| SKB outputs → 165 inputs | 1059 mm | 506 mm | 458 mm |
| 595 outputs → SKB inputs and MOSFET gate | 303 mm | 236 mm | 111 mm |
| Shift chains (MISO_ISO, SI_CHAIN, MOSI_ISO, SO_CHAIN) | 166 mm | 100 mm | 98 mm |
| Total of the swappable nets, including constants | 1543 mm | 860 mm | 678 mm |
| Control nets, MOSFET drain and MCU ↔ opto nets | 346 mm | 346 mm | 307 mm |
| Crossings among the swappable nets | 839 | 154 | 83 |
| Crossings, all of the above nets | 1000 | 297 | 112 |

As an independent check, the whole board (then 2 layers) was autorouted
with Freerouting 2.1 for 40 minutes, two versions side by side on the same
machine. (2.1 was built from source; 2.5 needs Java 25.) No run finished,
and Freerouting logged internal errors on all of them, but the trend is
clear:

| Freerouting 2.1, 40 min | Run 1: original | Run 1: pin swap | Run 2: pin swap | Run 2: pin swap + moved parts |
|---|---|---|---|---|
| Passes completed | 55 | 456 | 432 | 508 |
| Unrouted connections, best after 20 passes | 59 | 39 | 40 | 33 |
| Unrouted connections, best within 40 min | 55 | 30 | 31 | 30 |

Pin swapping made the biggest difference. Moving parts helped the router
early on (33 instead of 40 unrouted after 20 passes), but after 40 minutes
both pin-swapped boards ended at about 30. The runs were measurements only;
their routing was not kept. The outer ground pours went to Freerouting as
planes, so it treated every ground pad as connected and never routed
ground; the counts above leave ground out. The board has since gone to 4
layers and is routed (next section).

```
python3 scripts/optimise_placement.py --write   # placement search, about 8 min
~/.local/share/uv/tools/atopile/bin/python scripts/place_components.py
python3 scripts/pin_swap.py           # report: current map vs best found (about 5 min)
python3 scripts/pin_swap.py --write   # rewrite main.ato's pin map and the README tables
ato build                             # move the nets in the layout; placement is kept
```

### Planes and routing

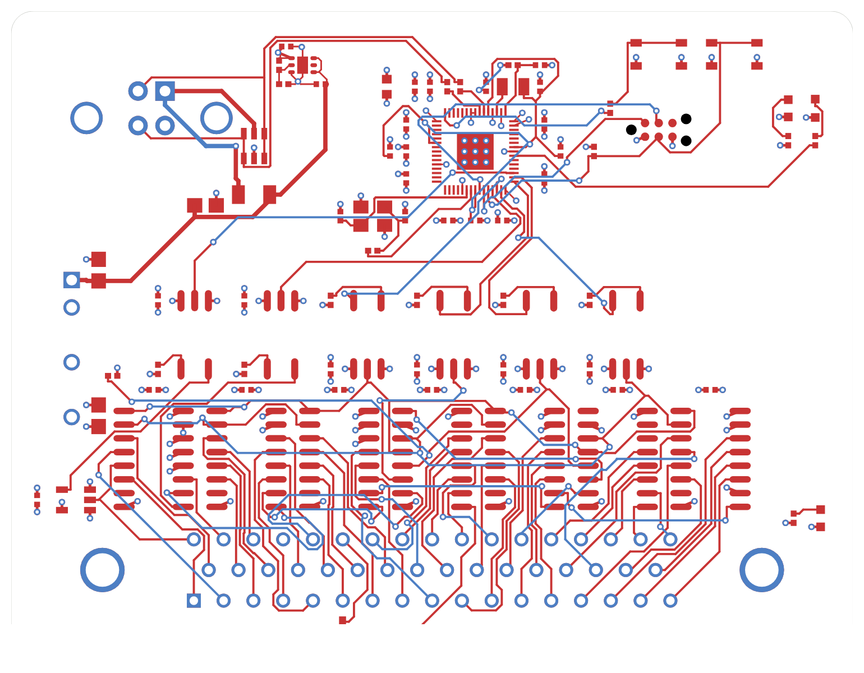
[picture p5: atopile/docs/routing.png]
routed board: F.Cu red, B.Cu blue


The board is 4 layers, with GND/GND_ISO on In1 and +3V3/+5V_ISO on In2
(see "Board"), so the autorouter has no ground or supply connections left
to route. It is fully routed:
* 1863 mm of track: 1438 mm on F.Cu, 425 mm on B.Cu.
* 198 vias: 149 on the four plane nets (nearly all of them via drops), 49
  on signals.
* Default net class 0.2 mm track and 0.15 mm clearance; VBUS and +5V use a
  0.4 mm Power class.

How it was routed:

1. **Plane via drops** (`scripts/plane_vias.py`). Freerouting barely uses
   planes: given the planes alone, it placed 58 vias in 40 minutes and left
   111 connections. So a script joins each of the 147 SMD pads on the four
   plane nets to its plane, with a short stub and a through via.
   * Each via keeps 0.2 mm from other nets' copper.
   * Vias stay out of the barrier keep-out and the jackscrew heads.
   * Vias stay out of the escape zones of other nets' IC pins, and out of
     two no-via areas at the RP2354A, on the USB pair and on VREG_LX.
   * The RP2354A's exposed pad gets 9 vias. Its pin 53 is strapped to pin
     54, and C22's +3V3 pad is left to the router.
2. **Freerouting 2.1** on the Specctra export (`scripts/export_dsn.py`),
   with the via drops and the pre-routed LDO block locked. Two fixes to its
   command-line mode are in `scripts/freerouting-2.1.0-cli-output.patch`:
   * A job that finished during the timeout's grace period wrote no
     session file.
   * The session file was a mid-pass board, not the best board Freerouting
     ends with. KiCad then found up to 30 open connections where
     Freerouting reported 3.
3. **Import** (`scripts/import_routing.py`). KiCad reads the session, and
   the tracks go into the layout through atopile's file model, so `ato
   build` still reads the board.
4. **Finish** (`scripts/finish_routes.py`). A small grid router (A*,
   0.05 mm grid, F.Cu/B.Cu and vias, with rip-up and reroute) closes what
   Freerouting left. Here that was 2 connections: C22's +3V3 pad and one
   LATCH_ISO branch.

Each Freerouting run below started from the unrouted board, with a 25- or
40-minute limit. A few stopped earlier, when Freerouting found nothing more
to improve. The table shows what each change bought:

| Board | Passes | Unrouted after 20 passes | Best unrouted | Change that followed |
|---|---|---|---|---|
| 2 layers, outer ground pours | 508 | 33 | 30, ground not counted | 4 layers, inner planes |
| 4 layers, planes only | 296 | 138 | 111 | plane via drops |
| + via drops, 0.25/0.2 mm rules | 758 | 27 | 23 | 0.2/0.15 mm default class: 0.25/0.2 mm left no way out of the RP2354A's 0.4 mm-pitch pins |
| + 0.2/0.15 mm rules | 843 | 5 | 3 | no via drops in IC escape zones (a cap's via sat under pins 27/28) |
| + escape zones | 999 | 5 | 2 | RP2354A decoupling caps 0.9 mm further out; the 1.2 mm channel could not hold SCK, CLK, MISO and N_RESET |
| + caps moved | 871 | 4 | 3 | USB series resistors swapped and turned: DP and DM had to cross |
| + USB resistors | 887 | 6 | 2 | no-via area on the USB pair's channel |
| + USB no-via area | 943 | 9 | 3 | no-via area on the VREG_LX path |
| + VREG_LX no-via area (final) | 755 | 4 | 3 | `finish_routes.py`: 2 connections, then 0 |

Freerouting's counts are its own. On the imported board, KiCad found 2 open
connections, and `finish_routes.py` routed both.

```
~/.local/share/uv/tools/atopile/bin/python scripts/place_components.py  # placement, stack-up, planes
python3 scripts/plane_vias.py --write          # via drops (report only without --write)
python3 scripts/export_dsn.py build/board.dsn
java -jar freerouting-2.1.0.jar --gui.enabled=false --router.job_timeout=00:25:00 \
     -de build/board.dsn -do build/board.ses   # 2.1.0 with the patch above; about 20 min
python3 scripts/import_routing.py build/board.ses
python3 scripts/finish_routes.py --write       # the last few connections
python3 scripts/export_pcb.py                  # DRC, gerbers, prints, renders
```

`python3 scripts/import_routing.py --clear` removes all routing except the
LDO block, to start again from an unrouted board. The placement script
leaves tracks where they are, so clear them before moving parts.

## PCB outputs (gerbers, prints, renders)

`scripts/export_pcb.py` writes `fab/` from the current layout:

| File | Contents |
|---|---|
| `fab/solartron_7075_usb_gerbers.zip` | Gerbers (4 copper layers, mask, paste, silk, Edge.Cuts) + Excellon drill (mm, PTH/NPTH) + drill maps + job file |
| `fab/gerbers/` | the same files, unzipped |
| `fab/solartron_7075_usb_prints.pdf` | 1:1 prints on A4: (1) top copper + silk, (2) bottom mirrored = as seen from the meter, (3) top assembly, (4) In1.Cu ground planes, (5) In2.Cu supply planes |
| `fab/renders/*.png` | KiCad 3D renders: top, bottom, iso |
| `fab/drc_report.rpt` | KiCad DRC after zone refill |

**DRC: no errors and no unrouted connections**, so the zip has no
`_UNROUTED_` suffix. Review the open items below before ordering. Print the
PDF at 100 % / actual size. Page 2, held against SKB, checks the DD-50 pin 1
and the outline.

The DRC warnings:
* 62 silk-over-copper and 178 silk-overlap warnings, from the EasyEDA
  footprints' silk and the reference designators. These are cosmetic but
  should be tidied.
* 1 footprint-mismatch warning on J1. The TC2030 footprint comes from the
  `programming-headers` package, not a KiCad library, so this is benign.

The script works on a temporary copy, so zone fills don't end up in the
atopile layout. The copy is moved onto the A4 sheet and gets a title block.

```
ato build
python3 scripts/export_pcb.py      # needs kicad-cli + pcbnew (KiCad 10) and pdfunite
```

## BOM (all LCSC)

| Qty | Part | LCSC |
|---|---|---|
| 1 | Raspberry Pi RP2354A (QFN-60, 2 MB flash) | C41378174 |
| 1 | Abracon ABM8-272-T3 12 MHz crystal | C20625731 |
| 1 | Abracon AOTA-B201610S3R3-101-T 3.3 µH (polarity-marked) | C42411119 |
| 1 | TI TLV75901PDRVR LDO (atopile `ti-tlv75901`) | C544759 |
| 1 | SHOU HAN BF 180 vertical USB-B | C6081376 |
| 1 | ST USBLC6-2SC6 | C7519 |
| 1 | LUTE 1206L050/36NR 500 mA PTC | C20616702 |
| 1 | YLPTEC IB0505LS-1WR3 isolated 5 V/5 V 1 W | C5369607 |
| 6 | Toshiba TLP2361 | C107626 |
| 5 | TI CD74HCT165M96 | C352828 |
| 2 | Nexperia 74HCT595D,118 | C282339 |
| 1 | TI SN74AHCT1G125DBVR | C7484 |
| 1 | 2N7002 | C8545 |
| 1 | Amphenol DD50P364TXLF vertical DD-50 plug | C5402574 |
| 2 | Alps SKRPACE010 (atopile `buttons`) | C139797 |
| 3 | KENTO 0603 LEDs, green ×2 and yellow (atopile `indicator-leds`) | C12624, C2287 |
| 1 | Tag-Connect TC2030 SWD footprint (atopile `programming-headers`) | – |
| 56 | 0402/0603/0805 basic passives (see `build/builds/default/default.bom.csv`) | |

Plus two 4-40 UNC jackscrews (check the thread of the meter's SKB screwlocks).

## Building

```
uv tool install --python 3.14 atopile==0.15.9
ato auth login     # the 0.15 part picker needs an atopile account
ato build
```

## Schematic

[`schematic/solartron_7075_usb.pdf`](schematic/solartron_7075_usb.pdf) has
five pages: an overview, then one page each for USB/power, the RP2354A, the
isolation barrier and the SKB interface.

atopile has no schematic output, because the `.ato` code is the schematic.
`scripts/export_schematic.py` builds one from the build outputs:
* netlist and references from the generated PCB
* values from the BOM
* each part's own `.kicad_sym` symbol

Every pin gets a net label, and each atopile module instance is boxed with
its address. The script then plots the PDF with `kicad-cli`. It also exports
the netlist back out of the schematic and fails unless it matches atopile's
netlist net for net.

The script also runs KiCad's ERC and writes `schematic/erc_report.rpt`.
Current result: **0 errors, 0 warnings**. To make the ERC meaningful the
script:
* gives every pin a real electrical type: passive for discrete parts, and
  types from the datasheets for the ICs (`PIN_TYPES` in the script)
* adds PWR_FLAGs only on the four rails that are fed through a passive part:
  GND, +5V (through the PTC), +1V1 (through L1) and VREG_AVDD (RC filter)
* writes symbol and footprint library tables
Removing the +5V flag makes the ERC report the undriven DC-DC input, which
confirms the check really runs.

```
ato build
python3 scripts/export_schematic.py   # needs kicad-cli (KiCad 9/10; made with 10.0.6)
```

## Notes on the tool (benchmark observations)

* atopile 0.15.9 is the last CLI release. Its package registry host
  (`packages.atopileapi.com`) does not resolve, so library packages are git
  dependencies on `github.com/atopile/packages`. The part picker needs
  `ato auth login`.
* `ato create part` searches through the authenticated API. Here the parts
  were imported with the same EasyEDA ingest path it uses
  (`download_easyeda_info` + `ingest_part_from_easyeda`).
* The picker sends the correct package filter, but the backend returned
  parts in the wrong packages (1210 and through-hole parts for 0402/0805
  requests). All passives are therefore pinned to JLC basic parts with
  `lcsc_id`.
* The library `LEDIndicator` module fails to solve on 0.15.9 (circular
  `current` constraint), so the LEDs are a resistor plus the library LED part.
* `override_net_name` on an `ElectricPower.hv/lv` is ignored, because the
  stdlib already puts a name trait there. Rails are named through a helper
  `signal`.
* After swapping parts, an incremental build left some pads unconnected.
  Regenerating the PCB fixed it.
* atopile's EasyEDA-derived symbols give every resistor/capacitor pin the
  type `input` and almost every IC pin `unspecified`. A raw ERC therefore
  reports 460 meaningless violations, so the exporter assigns real pin types.
* Symbols created by atopile's EasyEDA converter that contain a circle
  (e.g. the pin-1 dot) are written as `(circle (center ..) (end ..))`, which
  KiCad 10 refuses to load. The schematic exporter converts them to
  `(radius ..)`.
* Three of the EasyEDA 3D models were placed wrongly by the importer. The
  footprints and pads were correct. Fixed in `parts/` and the layout:
  * IB0505LS-1WR3: the model sat 2.05 mm off the pin row, which made the
    DC-DC look as if it overhung the board edge (offset y → 0).
  * BF 180 USB-B: the model origin is at the mating face, so the body sat
    under the board (offset z → 16.1 mm).
  * DD50P364TXLF: the model origin is at the flange, so the rear body and
    tails poked through the top face (offset z → 5.26 mm).
* Library modules with a pre-routed sub-layout (here `ti-tlv75901`) copy
  their tracks into the board at the library's coordinates. Moving the
  footprints with `PCB_Transformer.move_fp` leaves those tracks behind; the
  placement script moves the whole group instead.
* atopile has no pin-swap or back-annotation feature. Because the netlist is
  code, a swap is an edit to the `.ato` connections, so `scripts/pin_swap.py`
  regenerates a marked block of `main.ato`. `ato build` then moves the nets
  in the existing layout and keeps the placement.
* atopile's KiCad file model uses one `Polygon` type for both graphic
  polygons and zone outlines. A zone outline must not carry a `uuid`, or
  KiCad 10 refuses to load the board, so the placement script passes
  `uuid=None`.
* atopile has no setting for the layer count, the stack-up or planes. The
  placement script edits them through atopile's KiCad file model. Its lists
  are views into the file, so clearing one invalidates the items you just
  read from it: copy the fields out first. `ato build` keeps the 4-layer
  stack, the zones and any tracks.
* atopile 0.15 cannot read a board saved by KiCad 10 (new tokens such as
  via `tenting`), so KiCad must not save over the layout.
  `scripts/import_routing.py`, `scripts/plane_vias.py` and
  `scripts/finish_routes.py` therefore use KiCad's Python only to read the
  session or work out the geometry. They write the tracks and vias through
  atopile's own model.

## Open items before fabrication

Two earlier concerns are closed by manual §9, diagram 9.2:
* **Hi-Z = inactive:** confirmed, see "Safe at reset".
* **595 high of up to 5.25 V vs the "+5 V" input spec:** the inputs are
  standard TTL (5.5 V absolute max) with 4.7 kΩ pull-ups to the meter's
  +5 V. Only about 50 µA flows back.

Layout:
* Review the autorouted board in KiCad before ordering. The routing passes
  DRC, but no person has checked it yet. In particular:
  * VREG_LX and the RP2354A's +1V1 are 0.2 mm tracks; the RP2350
    datasheet layout keeps the regulator loop short and wide.
  * The USB pair is routed as two single tracks, not as a 90 Ω
    differential pair (full speed, 12 Mbit/s, so this is not critical).
  * Some tracks run between the DD-50 pins (Q1's drain and gate among
    them).
* Clean up the silkscreen (see "PCB outputs"). The schematic ERC is clean
  (see "Schematic").
* The shift-register row was first placed in reverse order relative to the
  DD-50: the placement script derived the order from the SKB pins and got
  the sign wrong once the DD-50 was on the bottom face. The DVM-side
  placement is now an explicit, generated table.
* Orient the RP2354A regulator inductor's polarity dot as in RP2350
  datasheet figures 26 and 28 (VREG_LX → DVDD).
* Check how the DD-50 mates now it is flipped onto the bottom face. Hold
  page 2 of `fab/solartron_7075_usb_prints.pdf` against SKB to confirm that
  plug pin 1 meets SKB pin 1 and that the D-shape lets the board extend the
  intended way.

Mechanical:
* Check the 7075 rear panel for clearance around the 78 × 60 mm outline. The
  board extends from the DD-50 towards the "north" (USB) edge.
* Confirm the thread of the SKB screwlocks. I assumed 4-40 UNC; a 1970s
  Cannon socket may differ. Then choose a jackscrew length for 1.6 mm board
  plus the flange.
* Stack-up, from the 3D models (confirm against the Amphenol drawing):
  * The DD-50 rear body is 5.3 mm, so the board's underside sits about
    5.7 mm above the plug flange's mating face. The meter's screwlock
    standoffs add to that.
  * Through-hole leads stick out below the board: the USB-B shell tabs by
    about 3.7 mm and the DC-DC pins by about 1.9 mm. Trim them so they clear
    the meter's rear panel.
  * The DD-50 tails stick out about 3.6 mm above the top face, and the USB-B
    stands 16.1 mm tall.

Parts:
* DD50P364TXLF currently shows no JLCPCB stock. It is a common Amphenol part
  (DigiKey/Mouser) and is through-hole, so hand-fit it or consign it. Every
  other part was in stock at JLCPCB when checked.
* Some details are inferred, because the manufacturer datasheets couldn't be
  downloaded here. Confirm them against the datasheets:
  * DD50P364TXLF is the vertical PCB-mount version with plain 3.1 mm flange
    holes. This came from LCSC data and the footprint.
  * SHOU HAN "BF 180" is a vertical USB-B. This came from the footprint's
    pin layout.
  * TLP2361 pinout (from the LCSC symbol) and its recommended IF(ON) for the
    ~4.5 mA LED drive. The logic type and threshold came from Toshiba's
    product page.

Electrical margins:
* The IB0505LS-1WR3 input is specified at 4.75–5.25 V. VBUS after the PTC can
  sag below that on a weak port or long cable. Check that +5V_ISO holds up,
  or use a wider-input isolated converter.

Firmware:
* None written yet. The protocol is in the "Firmware interface" section above.

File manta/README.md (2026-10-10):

# Solartron 7075 USB interface

An RP2354A-based, opto-isolated USB interface for the Solartron 7075 digital
multimeter, described in [Manta](https://github.com/Derrick-Derrickson/Manta).
It plugs straight onto the meter's 50-way D socket and lies flat against the
back of the instrument.

```
 USB-B ── ESD ── RP2354A ──┬─ 4 × TLP2361 ──▶ SCLK, DIN, LATCH, nOE ─┬─ 5 × 74HCT165 ◀── SKB 1-36 (meter outputs)
   │                       └─ 1 × TLP2361 ◀── serial data back ─────┘   2 × 74HCT595 ──▶ SKB 38-50 (meter commands)
   └── FB ── B0509S (isolated 1 W) ── HT7550 5 V ─────────────────────── meter-side logic, referenced to SKB 37
        USB ground (GND)        ║ isolation barrier ║        meter earth / logic 0 (ISO-GND)
```

Only five logic signals cross the barrier. Every meter-side part is powered
from the isolated converter and referenced to SKB pin 37, so the USB host's
ground never touches the meter.

## The interface it targets

The 50-way connector is **SKB of the Parallel BCD Interface Unit 70754**, the
interface documented in section 9 of the service manual (connection table on
page 9.9). That is the socket this board's pinout follows. A 7075 *without*
the 70754 fitted has only SK1 on its rear panel, which carries the meter's
internal word-serial bus instead and is **not** compatible with this board.

| SKB pins | Direction | Signals |
|---|---|---|
| 1–25 | meter → board | Staticised BCD: 1×10⁶, then 8/4/2/1 × 10⁵ … 10⁰ |
| 26, 27 | meter → board | Polarity: 10 = +, 01 = −, 00 = AC/Ω |
| 28, 29 | meter → board | Function: 11 DC, 01 AC, 10 Ω, 00 CHECK |
| 30–32 | meter → board | Range output (4, 2, 1) |
| 33, 34, 35, 36 | meter → board | PRINT pulse, PRINT level, DATA CAN CHANGE, OVERLOAD |
| 37 | — | Earth / logic 0 → ISO-GND |
| 38–50 | board → meter | Lockout, contact SAMPLE, pulse SAMPLE, RATIO, function, integration time, AUTORANGE, range |

Levels (manual p. 9.1): meter outputs high 2.4–6 V from 6 kΩ, low < 0.5 V at
10 mA; meter inputs high 2.4–5 V at 100 µA, low < 0.5 V at a 5 mA sink. The
input circuits (Diag 9.2) are TTL gates with 4.7 kΩ pull-ups, so an
undriven input reads 1.

## Layout of this folder

| Path | What |
|---|---|
| `src/board.manta` | The board, top block `solartron-7075-usb`, one `--- SECTION` per functional group |
| `src/*.manta` | One part per file with its datasheet excerpt after `---`; commodity passives share `passives.manta` |
| `solartron7075.mantaRules` | Project checks: logic levels, footprints present, every fitted part has an LCSC code |
| `solartron7075.fpmap` | Package → KiCad footprint translation |
| `footprints/Solartron7075.pretty` | Two generated footprints KiCad lacks (DD-50 vertical plug, polarised AOTA inductor land) |
| `tools/` | Footprint generator, LCSC BOM grouper, netlist verifier |
| `output/` | Netlist, KiCad netlist, HTML schematic, BOMs, verification report |
| `build.sh` | The whole build |
| `CONVERSATION.md` | The design session's log and statistics |

```sh
./build.sh
```

runs `fmt --check`, `compile`, `check -Werror` with the project rules, `link`
with the BOM, the KiCad `export` and `render` (both `-Werror`), then the
footprint generator, the LCSC BOM and the netlist verifier. Every stage was
silent on the committed sources. To use the KiCad netlist, add
`footprints/Solartron7075.pretty` to the project footprint table as
`Solartron7075`.

## Parts

From **manta's own part library** (`examples/blinky`), unchanged apart from an
added `#lcsc` code and, where the library left it open, an `#~mpn`:
AP2112K-3.3 LDO, USBLC6-2SC6 ESD array, 1 kΩ and 10 kΩ RC0603 resistors,
100 nF / 1 µF / 10 µF capacitors, the 0603 green LED, and the `usb2` harness.

Everything else was chosen from **LCSC**; `output/solartron7075-bom-lcsc.csv`
has one line per part with its LCSC code. All 98 placements have one.

| Ref | Part | LCSC | Why |
|---|---|---|---|
| U1 | RP2354A | C41378174 | As requested; 2 MB flash in package |
| U10–U14 | Toshiba TLP2361 | C107626 | 15 MBd optocoupler, 2.7–5.5 V output side, 1.3 mA threshold |
| U20–U24 | TI CD74HCT165M96 | C352828 | TTL-level inputs for the meter's 2.4 V highs |
| U30, U31 | Nexperia 74HCT595D | C282339 | 3-state outputs, 0.33 V at 6 mA for the meter's 0.5 V / 5 mA lows |
| PS1 | YLPTEC B0509S-1WR3 | C5369463 | 1 W isolated, 1.5 kV DC |
| U4 | UMW HT7550-1 | C347189 | 30 V-input 5 V LDO behind the unregulated 9 V |
| L1 | Abracon AOTA-B201610S3R3-101-T | C42411119 | The polarity-marked inductor the RP2350 datasheet requires |
| Y1 | Abracon ABM8-272-T3 | C20625731 | The crystal the RP2350 design guide specifies |
| J1 | Amphenol DD50P364TXLF | C5402574 | Vertical DD-50 plug with plain flange holes for jackscrews |
| J2 | TE 5787834-1 | C592900 | Vertical USB-B |
| J3 | JST SM03B-SRSS-TB | C160403 | Raspberry Pi debug-probe connector |
| RN1–RN18 | Uniroyal 4D03 10 k / 100 k | C29718 / C1996 | Series protection and pull-ups on the 36 meter outputs |

**Stock at design time (2026-10-10):** DD50P364TXLF showed 0 at LCSC (RS and
other distributors list it). LCSC's only stocked vertical DD-50 plug, CAX
DP-G-50P-ZC-YCLS (C54573066), has riveted board locks and female 4-40
screwlocks, which jackscrews cannot pass through, so it is not a drop-in
substitute. The AOTA inductor (109) and the JST header (15) were also low.

## Firmware interface

### Pins

| RP2354A | Net | Notes |
|---|---|---|
| GPIO2 | MCU-SCLK | SPI0 SCK. Inverted by the optocoupler |
| GPIO3 | MCU-MOSI | SPI0 TX. Inverted |
| GPIO4 | MCU-MISO | SPI0 RX. **True** polarity (inverted twice) |
| GPIO5 | MCU-LATCH | SPI0 CSn. Inverted |
| GPIO6 | MCU-OE | High enables the command outputs |
| GPIO25 | MCU-LED | Status LED, active high |

Use the RP2354's per-pin output inversion (or a PIO program) so the meter
side sees the intended levels. At reset the pins are high-impedance and
pulled low, every opto LED is dark and the '595 outputs are disabled, so the
meter sees no command until firmware enables them.

### One transfer

On the meter side this is SPI mode 0: SR-CLK idles low, both chains shift on
its rising edge, and the '165 presents bit 1 as soon as it is loaded.

1. Hold **MCU-SCLK high** (meter-side clock low). The 74HCT165 datasheet
   requires CP low when PL rises.
2. Pulse **MCU-LATCH high, then low**: the '165s capture all 40 inputs, and
   the rising edge of SR-LATCH copies the command shifted in last time onto
   the '595 outputs.
3. Clock 40 bits. For each bit: put the *complement* of the command bit on
   MCU-MOSI, read MCU-MISO, then take MCU-SCLK low and back high.

Keep the clock at or below about 1 MHz: each optocoupler adds up to 80 ns and
MISO comes back through two of them plus the '165.

Before the first `MCU-OE` high, run one transfer and one latch so the '595s
hold a known command (all ones is "no command").

### Bits read on MISO (1 = first after the latch)

| Bits | Content |
|---|---|
| 1–36 | SKB pins 1–36, in order: bit *n* is SKB pin *n* |
| 37 | Always 1 |
| 38 | Always 0 |
| 39 | nSR-OE as the meter side sees it: 1 = commands disabled |
| 40 | The SKB 38 command bit from the previous transfer, read back from the end of the '595 chain |

With the board unplugged from the meter, bits 1–36 read 1 through the
pull-ups, so every BCD digit reads 0xF.

### Command bits (the last 16 shifted in; 1 = first of them)

| Bit | SKB | Meaning (manual pp. 9.2–9.4) |
|---|---|---|
| 1 | 38 | FRONT PANEL LOCKOUT, 0 = locked out (puts the meter in REMOTE) |
| 2 | 39 | CONTACT SAMPLE, 0 = contact closed |
| 3 | 40 | PULSE SAMPLE: 1 for > 10 µs, then 0, takes a reading |
| 4 | 41 | RATIO, 0 = ratio (DC and AC only) |
| 5, 6 | 42, 43 | Function (43, 42): 11 DC, 01 AC, 10 Ω, 00 CHECK |
| 7–9 | 44–46 | Integration time (4, 2, 1): 011 1 ms, 100 20 ms, 101 100 ms, 110 1 s, 111 10 s |
| 10 | 47 | AUTORANGE: 1 = use the commanded range, 0 = autorange |
| 11–13 | 48–50 | Range (1, 2, 4), table on p. 9.3; 111 = autorange |
| 14–16 | — | Spare |

A reading is ready when bit 34 (PRINT level) is 1; bit 35 (DATA CAN CHANGE)
is its complement. The manual's timing is on p. 9.8.

`output/verify.txt` is these two maps derived from the netlist itself rather
than from this text.

## Layout notes

- **J1 on the bottom side, J2 on the top.** J1 is a through-hole part placed
  on the bottom (KiCad mirrors it); its two `SH` pads are the 3.2 mm
  jackscrew holes and the board's only fixing. All SMD parts go on the top.
- **Isolation gap.** Keep a continuous copper-free gap between the GND and
  ISO-GND domains, crossed only by U10–U14 and PS1. No pour, plane or trace
  may span it. PS1 is rated 1500 V DC for 1 minute and the TLP2361 3750 Vrms;
  the gap width is a layout decision this schematic does not make.
- **RP2354A core regulator.** Copy the RP2350 datasheet's Figure 26: C21, C22,
  L1, C24/R3 on the top side, tight loops, copper cut away under L1. L1's
  pad 1 (silkscreen dot) is the dotted end and goes to 1V1.
- **TLP2361 bypass** capacitors within 1 cm of pins 4 and 6.
- **USB pair** at 90 Ω differential through U2 and R1/R2.

## Notes on the tool (benchmark observations)

Manta 2.0.1, language revision 2.0. Each point below was hit or checked
during this design.

* **The install is a bare binary.** `~/.local/share/manta` holds only the two
  JSON schemas. The language specification, the agent skills (house style,
  idioms, the meaning of each diagnostic) and the only part library live in
  the source checkout, which had to be found on disk; `manta --help` points
  to none of them.
* **"Manta's library" is one example board.** There is no part library as
  such: the parts are the declarations in `examples/blinky`, which are five
  resistor values, three capacitors, two LEDs, an AP2112K LDO, a USBLC6 ESD
  array, an STM32F042, a DIP switch, three board connectors and some cable
  parts. Nothing can be installed or imported, so the 8 part types used here
  were copied into `src/` with an `#lcsc` field added. The other 21 were
  written by hand.
* **No part import.** Manta cannot take a symbol or footprint from
  LCSC/EasyEDA or KiCad. Every new part's pin map, arrows and `&TYPE`s were
  typed from its datasheet, together with the datasheet excerpt the house
  style puts after `---`. For the RP2354A that is 61 pads, whose QFN-60 map I
  had to rebuild from the coordinates of the datasheet's pinout figure.
* **The compiler cannot see a footprint.** A part names a package
  (`@~footprint = SOIC-16`) and the `.fpmap` translates it to a KiCad name.
  Nothing checks that the footprint exists or that the part's pin numbers are
  pads on it; `export -Werror` only insists on a `Library:Footprint` form. A
  pin on a pad the footprint lacks connects nothing, silently. I checked the
  pad names of every non-standard footprint here (the QFN-60, Toshiba SO-5,
  USB-B, SIP-4, crystal, switch, JST, resistor array and SOT-89) against
  KiCad's library files by hand.
* **No layout, and no way to state mechanical intent.** Manta stops at the
  netlist; its exports are netlists, not KiCad schematic or board files. The
  brief's mechanical requirements (board outline, which face each connector
  is on, jackscrew fixing, no mounting holes) could only go into comments and
  free `#` fields (`#mount`, `#hardware` on J1 and J2). `&EDGE` sounds
  relevant but is display-only: it says which edge of the *schematic sheet* a
  connector faces.
* **Isolation is invisible to ERC.** Two `&TYPE=GROUND` nets are allowed, and
  nothing checks that they stay apart. With one optocoupler's LED cathode moved
  to the wrong ground, the design still passes `check -Werror` with the
  project rules. The rules language works per net, per part, per component or
  per pin pair on one net, so a check that follows connectivity across the
  board had to be a separate script, `tools/verify_netlist.py`.
* **Duplicate designators pass silently.** In Manta's own `blinky` example,
  `AGND = (.{R9~R-0R-0603}.)|2 = GND;` creates two resistors that are both
  `R9`: two BOM rows and two `R9` components in the KiCad netlist. The example
  passes `check -Werror` with its rules and no findings. Manta's idioms say to
  give such a group a range designator (`R%[9:10]`), but the compiler does not
  enforce it.
* **A stray character cascades.** `@~footprint = QFN-60-7x7-EP3.4;` gave six
  `E-SYNTAX` errors at the same column. The first ("expected ';' … found
  '.'") locates it; the other five are the parser losing its place. Package
  names cannot contain `.`.
* **Harness nets have no pins.** Each harness (`USB`, `MCU-USB`, …) appears in
  `.mantaNets` as a net with no pins and only a `HARNESS` directive, so
  anything that reads the netlist has to skip them.
* **The BOM is one row per placement.** `link --bom` lists every designator
  separately, with every `#` field as a column; the grouped LCSC BOM needed a
  script, `tools/lcsc_bom.py`.
* **Rendering needs a browser to check.** `manta render` writes one
  self-contained HTML file, and its PDF option drives a headless Chromium.
  None was available here, so the schematic passed `render -Werror` but was
  never looked at.

## What has and has not been verified

Verified, by running it:

- `manta check -Werror` with the project rules: no findings. The rules were
  mutation-tested: a '595 VOL of 0.6 V, a 1.9 V opto VOH and a missing LCSC
  code are each reported.
- `link`, KiCad `export` and `render`, all under `-Werror`.
- `tools/verify_netlist.py`: the two ground domains (33 USB-side and 102
  meter-side nets) meet only through the five optocouplers and PS1, each
  oriented correctly; and the bit order above is simulated from the netlist.
  Rewiring one opto's LED to the wrong ground makes it fail, which manta's own
  checks do not catch.

Not verified:

- No PCB has been laid out, so there is no DRC and no 3D check of J1 against
  the meter's socket.
- The two generated footprints were drawn from the manufacturers' drawings
  but have not been opened in KiCad or checked against a physical part.
- The rendered schematic passed `render -Werror` but was not inspected by eye.
- No firmware has been written.
- Current draws are estimates (about 15–20 mA on the meter side, under
  150 mA from USB); the RP2350 datasheet gives no single active-current
  figure to put on the budget, so the design carries no `#DRAW` rule.
- That the meter has a 70754 fitted, as discussed above.

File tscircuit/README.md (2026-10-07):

# Solartron 7075 USB interface (tscircuit)

An RP2354A USB interface for the Solartron (Schlumberger) 7075 DVM. It plugs into
socket **SKB**, the 50-way D on the **70754 Parallel BCD Interface Unit**
(manual Section 9, `../inputs/solartron_7075_service_manual.pdf`). The board can
read every DVM output and drive every remote command. All DVM signals are
optically isolated from USB ground.

```
USB-B ─ ESD ─┬─ AP2112K 3.3 V ─ RP2354A ── SPI0 ──┐
             │                                     │  5 x TLP2361 optocouplers
             └─ ferrite ─ B0505S-1WR3 (isolated) ──┼───────────────────────────
                             │                     │
                         HT7533 3V3_ISO     SCK MOSI LATCH OE_N │ MISO
                                                   │            │
                     2 x 74LV595A ─ 2 x 74LVC07A ──┤      5 x 74LV165A
                       (13 commands, open drain)   │      (36 DVM outputs)
                                                   └── DD-50 plug ── SKB (70754)
```

## Files

| Path | Contents |
| --- | --- |
| `index.circuit.tsx` | Board outline, copper pours either side of the barrier, top-level assembly |
| `lib/sections/UsbPower.tsx` | USB-B socket, USBLC6 ESD, 3.3 V LDO, DC-DC input filter |
| `lib/sections/Mcu.tsx` | RP2354A, core regulator, crystal, BOOTSEL/RUN, SWD pads, LEDs |
| `lib/sections/Isolation.tsx` | TLP2361 barrier and isolated DC-DC converter |
| `lib/sections/DvmInterface.tsx` | Isolated 3.3 V, shift registers, open-drain drivers, D-sub |
| `lib/solartronSkb.ts` | SKB pin table transcribed from manual p. 9.9 |
| `lib/dvmPlacement.ts` | Positions of the command-side parts (595s, buffers, pull-ups, R20, R21) |
| `lib/dvmPinMap.ts` | Which shift-register, buffer and pull-up pin serves each SKB signal, and the resulting firmware bit maps |
| `lib/DSub50MaleVertical.tsx` | DD-50 vertical plug footprint (no LCSC/EasyEDA footprint available) |
| `lib/passives.tsx` | Resistor/capacitor values pinned to LCSC part numbers |
| `lib/schLayout.ts` | Schematic grouping helpers (decoupling caps per rail) |
| `outputs/` | Exported schematic, PCB prints and renders, netlist and Gerbers of the routed board |
| `scripts/` | Export, fabrication fix-up, print and verification scripts (see below) |
| `lib/common/` | Parts reused from [tscircuit/common](https://github.com/tscircuit/common) (MIT) |
| `imports/` | Parts imported from LCSC/JLCPCB with `tsci import` |

## Build

```sh
cd tscircuit
npm install
npm run build      # tsci build: place, autoroute (~5 min), dist/index/{circuit.json,pcb.png,schematic.png}
npm run check      # netlist + placement DRC, copper shorts, isolation barrier check
npm run export     # outputs/: schematic, Gerbers, PCB prints/renders, netlist (from dist, no re-route)
```

`npm run export` makes the Gerbers in three steps:

1. `scripts/prepare-fab.mjs` writes `dist/fab/circuit.json`, a copy of the
   routed board with two `tsci` export problems fixed. Copper, mask, silk and
   drill geometry are unchanged:
   - **Solder paste.** tscircuit 0.0.2745 gives pill and polygon pads no paste,
     which is every SOIC, TLP2361 and the SOT-89 tab. It also puts paste on
     every through-hole and uses 70 % apertures, which are too small for the
     RP2354A's 0.2 mm pins. The stencil is rebuilt with 1:1 apertures, a 2 x 2
     windowpane on the RP2354A exposed pad, and no paste on through-holes.
   - **`%LR` rotation.** U2's and U3's pads are written as a rotated aperture,
     using the Gerber `%LR` command. Older viewers and CAM tools ignore `%LR`,
     and U3's pads then merge into shorts. These pads are rewritten as plain
     rectangles of the same outline.
2. `tsci export -f gerbers` turns that copy into `outputs/gerbers.zip`.
3. `scripts/pcb-prints.mjs` renders `gerbers.zip` with tracespace into
   `pcb-prints.pdf` and `pcb-render-{top,bottom}.png`. The prints therefore show
   exactly what the fab receives.

The routed result is committed in `outputs/`:

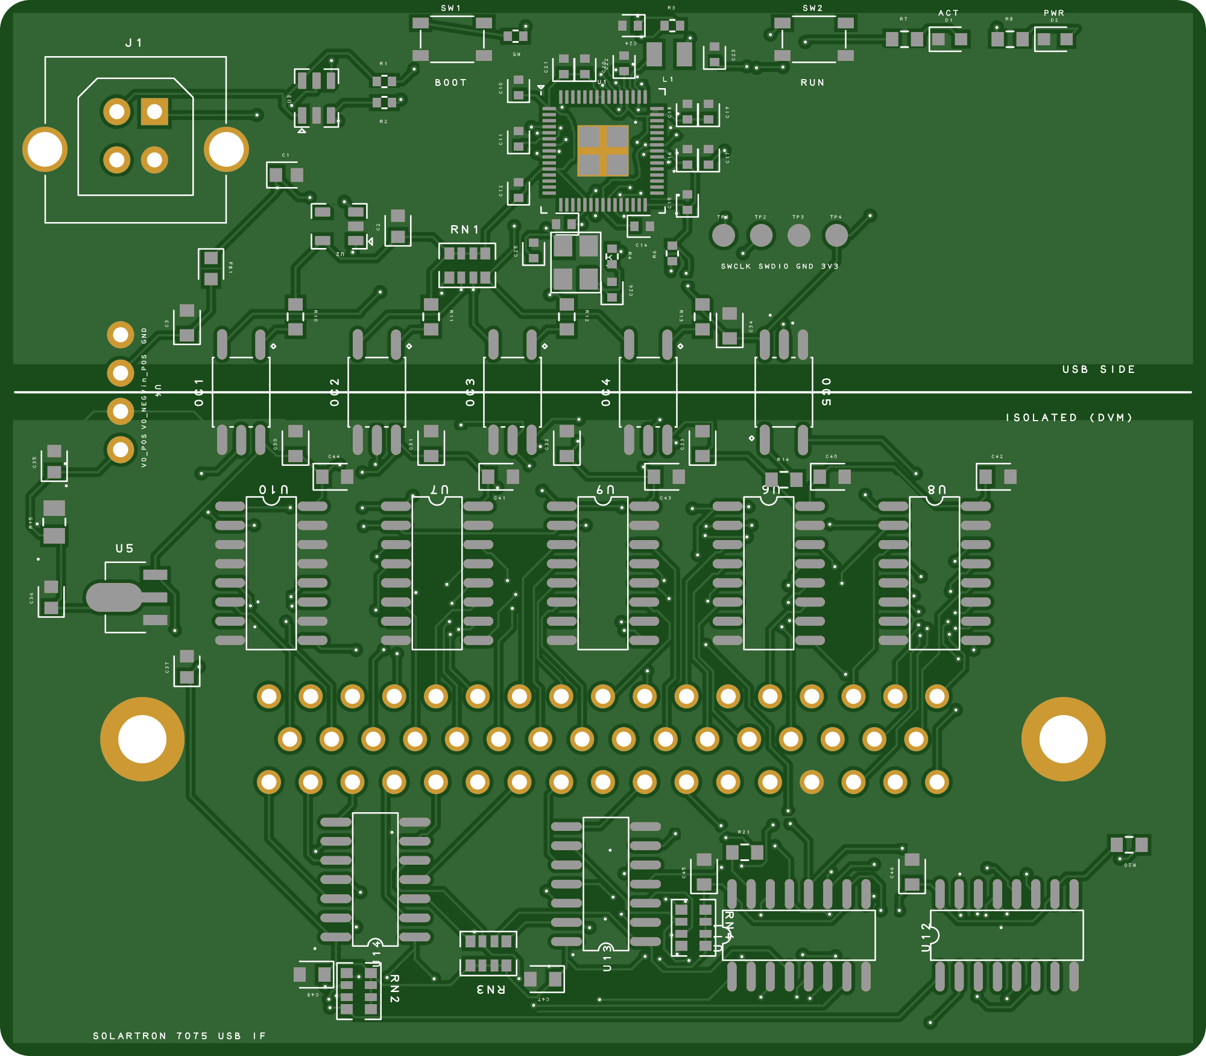
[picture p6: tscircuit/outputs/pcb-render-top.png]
Top side, rendered from the Gerbers


- `gerbers.zip`: Gerbers (X2, mm) and an Excellon drill file, with `bom.csv` and
  `pick_and_place.csv` carrying JLCPCB part numbers. Upload it to JLCPCB as it is.
- `pcb-prints.pdf`: seven A4 landscape sheets. Print them at 100 %; a scale bar
  on every sheet checks the size.
  1. Top and bottom views at 1:1, to check fit against the 70754.
  2. Top copper, 2:1.
  3. Bottom copper, 2:1.
  4. Top assembly, 2:1, with reference designators.
  5. Bottom assembly, 2:1, mirrored.
  6. Top stencil, 2:1.
  7. Drill drawing and drill table, 2:1.

  Every sheet is vector except the two renders on sheet 1.
- `pcb-render-top.png` and `pcb-render-bottom.png`: photo-style renders made
  from the Gerbers.
- `schematic.svg` and `schematic.pdf`. The PDF is a vector page at A1 width,
  made by `scripts/svg-to-pdf.mjs`, because `tsci`'s own PDF export is a
  144 dpi bitmap.
- `pcb-top.svg` and `pcb-bottom.svg`: tscircuit's own PCB views.
- `netlist.txt`.

The board is 2 layers, with 0.15 mm tracks and 0.2 mm/0.45 mm vias, which
JLCPCB builds at standard pricing.

Verification of the committed board:

- Every connection is routed and `tsci check shorts` passes.
- `scripts/check-isolation.mjs` finds no trace or via crossing the barrier.
- The Gerbers were checked in an independent viewer (tracespace), and the
  prints are drawn from it. Against the plain `tsci` export, copper, mask, silk,
  outline and drill are identical once aperture numbering is normalised, apart
  from the 11 U2/U3 pads rewritten without `%LR`. Only the paste layers differ
  in substance.
- The build reports no DRC errors.
- The tscircuit autorouter (capacity-autorouter 0.0.958) is very sensitive to
  small placement changes. Re-run `npm run check` after any edit, because a new
  route can differ.
- Check JLCPCB pick-and-place rotations in their preview. The exporter cannot
  verify pin-1 rotation for the SOICs and some imported parts.

## Routing

On the DVM side, the pins are assigned and the command-side parts placed to
suit the routing, not the bit order:

- **74LV165A inputs.** These parts stay where they were.
  - Above the D-sub, the traces run in x order across both pin rows, so each
    74LV165A reads the eight SKB pins nearest it.
  - The outer pins go to the upper pads of each pad column, so the fan-in
    doesn't cross itself.
  - The chain runs from one side of the board to the other, with U8 (x = 22)
    driving MISO, instead of zig-zagging between the chips.
- **Commands.** The positions and rotations of the 74LV595As, 74LVC07As,
  pull-up arrays, R20 and R21 were chosen by simulated annealing, together
  with which 595 output, buffer channel and pull-up element each command uses.
  The annealing minimises crossings between straight connection lines, and
  each chip's decoupling cap moves with it. The positions are in
  `lib/dvmPlacement.ts`.
  - The buffers stand on end under their D-sub pins, so their outputs run
    straight up to the connector.
  - The 595s lie along the bottom edge and feed the buffers along a bus.
- **Picking the route.** The autorouter is chaotic, so several of the
  best-scoring layouts were routed. I kept the one with the least routing and
  no DRC errors.

| | Original | Pin swap | Pin swap + moved parts |
| --- | --- | --- | --- |
| Connection-line crossings, 74LV165A side | 321 | 52 | 52 |
| Connection-line crossings, command side (incl. control and supply lines) | 288 | 158 | 37 |
| Track length (DVM side) | 3520 mm (2738 mm) | 2780 mm (2017 mm) | 2643 mm (1878 mm) |
| Vias (DVM side) | 385 (307) | 248 (175) | 227 (154) |
| DRC errors | 1 | 0 | 0 |

Below the D-sub alone, where the parts moved, track length fell from 915 mm to
817 mm and vias from 91 to 67 against the pin-swap version.

## Mechanical

- The board is 80 x 70 mm, 2 layers, with no mounting holes. It hangs off the D-sub.
- **J2 (DD-50 plug, vertical) is on the bottom side** and faces the 70754. Fit
  4-40 UNC jackscrews through J2's 3.2 mm flange holes into SKB's screwlocks.
- **J1 (USB-B, vertical) is on the top side**, so the cable leaves straight out
  the back.
- All SMD parts are on the top side. The only parts on the bottom side are J2 and
  the THT leads of J1 and U4. Trim those leads short, because the bottom face
  sits a few mm from the 70754 housing.

## Isolation

- The barrier is the row of optocouplers across the board (silkscreen line,
  `BARRIER_Y` in `Isolation.tsx`). `GND`/`V3V3` (USB) are above it and
  `GND_ISO`/`V3V3_ISO` (DVM) are below. Both copper pours stop 1.6 mm either
  side of the line, and a 1.8 mm copper `<keepout>` on both layers stops the
  autorouter from taking any trace or via across it. This gives ≥ 4 mm
  pad-to-pad creepage through each TLP2361. `scripts/check-isolation.mjs`
  checks the routed board. The aim is to break ground loops and keep USB noise out of the DVM.
  It is not a safety isolation design.
- SKB has no supply pin. The isolated side is therefore powered by a
  B0505S-1WR3 1 W module followed by an HT7533 LDO. R15 (470 Ω) provides the
  module's 10 % minimum load.
- Only five signals cross the barrier: SCK, MOSI, LATCH and OE_N to the DVM side, and MISO back.

### Why 3.3 V logic, 74LV165A and open-drain outputs on the DVM side

- The manual (p. 9.2) says an unconnected interface reverts to "DC, 10 s". That
  means SKB inputs float to logic 1, so they are meant to be pulled low by
  contacts or open collectors. Every command except pulse-sample goes through a
  74LVC07A open-drain buffer. These buffers have Ioff, so **when the board is
  unpowered the D-sub lines are high impedance and the DVM front panel works
  normally**. A push-pull 74HC595 would pull FRONT PANEL LOCKOUT (pin 38) low.
- The 74LV165A inputs are 5.5 V tolerant and have Ioff, and at 3.3 V their VIH is
  2.31 V. They therefore read the 70754's TTL outputs (VOH ≥ 2.4 V) directly,
  with no pull-ups, and nothing back-feeds the isolated rail from the DVM.
- The 74LVC07A inputs have 10k pull-ups and the 74LV595A outputs stay disabled
  (OE_N high) until firmware enables them. At power-up every DVM input therefore
  stays at its idle 1.
- Pin 40 (pulse sample, +3 to +8 V) is driven push-pull from a spare 74LV595A
  bit through 100 Ω. 3.3 V meets the +3 V minimum. Pin 39 (contact sample) is
  the preferred trigger.

## Firmware interface

RP2354A pins: GPIO2 = SCK, GPIO3 = MOSI (SPI0 TX), GPIO4 = MISO (SPI0 RX),
GPIO5 = LATCH, GPIO6 = OE_N, GPIO25 = activity LED. Every link is
non-inverting: GPIO low means the DVM-side signal is low. The TLP2361 is
specified to 15 Mbit/s, but the MISO round trip is about 200 ns, so run SPI
mode 0 at ≤ 2 MHz (one 40-bit frame takes about 20 µs at 2 MHz).

One transaction:

1. Drive LATCH low for at least 1 µs, then high. The low phase makes the
   74LV165As capture the DVM outputs. The rising edge loads the 74LV595A
   outputs with the previous frame's last 16 bits.
2. Clock 40 bits (5 bytes) MSB first.
   - **MISO:** bit k (k = 0 ... 39, first bit received = 0) reads the SKB pin
     in the MISO table below. Spare bits read 0.
   - **MOSI:** the last 16 bits clocked out are the command word, b15 first,
     b0 last. Writing a command takes effect at the next LATCH rising edge, so
     to change commands send the frame, then pulse LATCH again.
3. After the first frame, drive OE_N low to enable the outputs. It is pulled
   high, so the command outputs are disabled while the RP2354A is in reset or
   BOOTSEL.

The bit order is not the SKB pin order. Shift-register pins were assigned to
untangle the routing, as described under Routing. `lib/dvmPinMap.ts` holds the
assignment, and it exports the two maps below as `MISO_BITS` and
`COMMAND_BITS` for firmware.

MISO: the SKB pin read in each bit. The meaning of each pin is in
`lib/solartronSkb.ts`: pins 1-25 are BCD 1x10^6 ... 1x10^0, 26-27 polarity,
28-29 function, 30-32 range, 33 PRINT pulse, 34 PRINT level, 35 DATA CAN
CHANGE and 36 overload.

| Bits | +0 | +1 | +2 | +3 | +4 | +5 | +6 | +7 |
| --- | --- | --- | --- | --- | --- | --- | --- | --- |
| 0-7 (U8) | 2 | 19 | 36 | 3 | 34 | 1 | 18 | 35 |
| 8-15 (U6) | 22 | 6 | 23 | 7 | 20 | 4 | 21 | 5 |
| 16-23 (U9) | 26 | 10 | 27 | 11 | 24 | 8 | 25 | 9 |
| 24-31 (U7) | 30 | 14 | 31 | 15 | 28 | 12 | 29 | 13 |
| 32-39 (U10) | 33 | 17 | - | - | - | - | 32 | 16 |

Command word: write the manual's logic levels directly (1 = high/idle).

| bit | SKB pin | function |
| --- | --- | --- |
| 0 | 40 | PULSE SAMPLE (push-pull, idle 0, pulse > 100 µs) |
| 1 | 47 | AUTORANGE inhibit (1 = use range command) |
| 2 | 44 | integration time 4 (with 45, 46: 011 1 ms ... 111 10 s) |
| 3 | 46 | integration time 1 |
| 4 | 42 | function select (43, 42: 11 DC, 01 AC, 10 Ω, 00 check) |
| 5 | 45 | integration time 2 |
| 6 | 48 | range 1 |
| 7 | 49 | range 2 |
| 8 | 39 | CONTACT SAMPLE (0 = contact closed) |
| 9 | 50 | range 4 |
| 10 | 43 | function select |
| 11, 12 | - | spare (U12 QD, QE, unconnected) |
| 13 | 38 | FRONT PANEL LOCKOUT (0 = lockout) |
| 14 | 41 | RATIO (0 = ratio) |
| 15 | - | spare (U12 QH, unconnected) |

The idle word is `0x67FE`. A reading is complete when PRINT level (SKB pin 34,
MISO bit 4) is 1. The level stays high until the next sample, so polling is
enough and no interrupt line is needed.

## Bill of materials

Parts come from tscircuit/common first, then from LCSC.

| Ref | Part | LCSC | Source / note |
| --- | --- | --- | --- |
| U1 | RP2354A (RP2350A + 2 MB flash), QFN-60 | C41378174 | LCSC |
| U2 | AP2112K-3.3TRG1 LDO | C23380830 | tscircuit/common |
| U3 | USBLC6-2SC6 ESD | C7519 | LCSC |
| U4 | B0505S-1WR3 isolated 1 W DC-DC (HI-LINK) | C5183119 | LCSC |
| U5 | HT7533-1 LDO, 30 V in | C14289 | LCSC basic |
| U6-U10 | SN74LV165ADR | C273656 | LCSC |
| U11, U12 | SN74LV595ADR | C205940 | LCSC |
| U13, U14 | SN74LVC07ADR | C7659 | LCSC |
| OC1-OC5 | TLP2361(TPL,E) 15 Mbit/s optocoupler | C107626 | LCSC |
| J1 | USB-B vertical, THT (SHOU HAN BF 180) | C6081376 | LCSC |
| J2 | DD-50 plug, vertical PCB, Amphenol DD50P364TXLF | C5402574 | LCSC lists it but stock is 0. Alternatives: Assmann A-DS 50 PP/Z, Norcomp 171-050-103L001 (standard footprint) |
| Y1 | ABM8-272-T3 12 MHz | C20625731 | LCSC. This is the RP2350 datasheet's required crystal, used instead of common's X322512MSB4SI |
| L1 | AOTA-B201610S3R3-101-T 3.3 µH | C42411119 | LCSC. This is the RP2350 regulator inductor |
| FB1 | BLM18PG121SN1D | C14709 | tscircuit/common |
| SW1, SW2 | SKRPACE010 | C139797 | tscircuit/common |
| D1, D2 | XL-1608SURC-06 | C965799 | tscircuit/common |
| C1, C2, C35-C37 | CL10A106KP8NNNC 10 µF 0603 | C19702 | tscircuit/common |
| RN1-RN4 | 4D03WGJ0103T5E 4 x 10k | C29718 | LCSC basic |
| passives | see `lib/passives.tsx` | | LCSC basic where available |

## Assumptions and caveats

- This assumes the 70754 unit is fitted and the board mates with its SKB
  socket. The raw DVM socket behind the 70754 (PLA/SK1) carries a different,
  serialised interface.
- SKB and PLA are listed as "50 way Cannon" (DD-50, plug on the 70754 side of
  PLA, socket SKB). Check SKB's gender and screwlock thread on the actual unit
  before ordering J2.
- The manual does not state the input pull-up values. Open-drain drive relies
  on the inputs idling high, which the manual describes. If a particular input
  turns out not to have a pull-up, add one on the DVM side to the 70754's +5 V,
  not to `V3V3_ISO`.

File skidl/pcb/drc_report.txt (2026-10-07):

** Drc report for solartron_7075_interface.kicad_pcb **
** Created on 2026-10-07T06:03:25 **
** Report includes: Errors, Warnings, Exclusions **

** Found 0 DRC violations **

** Found 0 unconnected pads **

** Found 0 Footprint errors **

** Ignored checks **
    - Footprint has no courtyard defined
    - Track endpoint not centered on via
    - Tuning profile track geometries
    - Footprint doesn't match symbol's footprint filters
    - Footprint component type doesn't match footprint pads

** End of Report **

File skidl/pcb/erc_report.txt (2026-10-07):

ERC report (2026-10-07T03:29:25, Encoding UTF8)
Report includes: Errors, Warnings, Exclusions

***** Sheet /

 ** ERC messages: 0  Errors 0  Warnings 0

 ** Ignored checks:
    - Global label only appears once in the schematic
    - Four connection points are joined together
    - SPICE model issue
    - Assigned footprint doesn't match footprint filters

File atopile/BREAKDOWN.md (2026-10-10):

# Token breakdown of the original design work: method and caveats

These notes go with the atopile table under "Breakdown" in the root README.

## Span

The span is the same as the atopile row in the root README's Results table
and [`CONVERSATION.md`](CONVERSATION.md):
* It starts at the first prompt (2026-10-06 10:38 UTC).
* It stops just before the request to export the conversation (19:34 UTC).
  The last call in the span is at 18:48.
* It covers 10 user turns, ending with "commit and merge into main" and
  "make a branch `start`".

The review comments and everything after them are left out. Those are in
[`REVIEW_CONVERSATION.md`](REVIEW_CONVERSATION.md).

## API calls by category

There are 370 API calls, counting each assistant `message.id` once. The
calls fall into these blocks, in order:

| Time (UTC) | Calls | Active | Category | What the calls did |
|---|---|---|---|---|
| 10:38–10:40 | 13 | 1.8 min | Schematic & research | read section 9 of the manual; install atopile |
| 10:40 | 1 | 0.1 min | Other | task list |
| 10:40–10:59 | 101 | 18.7 min | Schematic & research | atopile docs and sources; registry, LCSC and JLCPCB part searches; datasheets; part import; pinouts |
| 10:59 | 2 | 1.1 min | PCB | board-shape and auto-layout docs |
| 11:00–11:24 | 52 | 25.0 min | Schematic & research | writing the `.ato` modules; builds; LED and passive fixes; netlist checks; net names |
| 11:25–11:34 | 31 | 9.8 min | PCB | outline, placement script, layout checks, zones |
| 11:35–11:39 | 17 | 4.1 min | Other | choosing what to commit (unused parts, STEP sizes), README, commit, summary |
| 12:06–12:20 | 41 | 13.9 min | Schematic & research | KiCad install; schematic exporter; net labels |
| 12:20–12:21 | 8 | 0.7 min | Other | README, commit, summary |
| 12:29 | 1 | 0.7 min | Schematic & research | JLCPCB stock check |
| 12:29 | 3 | 0.6 min | Other | README open items, commit |
| 12:34–12:39 | 17 | 5.1 min | Schematic & research | ERC; manual section 9 (board 2 pull-ups) |
| 12:39 | 3 | 0.5 min | Other | README findings |
| 12:40 | 1 | 1.1 min | Schematic & research | rebuild, regenerate schematic |
| 12:41–18:18 | 5 | 0.6 min | Other | commit; sending the schematic PDF |
| 18:22–18:41 | 54 | 20.5 min | PCB | DRC, gerbers, prints, renders; LDO block placement; 3D-model offsets |
| 18:42–18:48 | 20 | 2.1 min | Other | README, commit, merge into `main`, `start` branch |

## How the figures were measured

* **Active time.** Each call is credited with the time until the next call in
  the same turn. The first call of a turn also gets the time from the
  prompt. The last call runs to the end of the turn. These are the same turn
  boundaries as the Results row, so the calls add up to its 1 h 46 min, and
  "Not attributable" time is 0.
* **Tokens.** Each call's logged usage, counted once per `message.id`:
  input + cache writes + cache reads + output.
* **Prices.** Per-token prices were fitted by least squares to the 9
  distinct `cost-state` snapshots of the main model in the session. Per
  million tokens they are:
  * input $3.95
  * cache write $7.99
  * cache read $0.20
  * output $20.03

  They reproduce every snapshot to within $0.005.
* **Not attributable.** This is the Results-row totals minus the three
  categories: 4.6 M tokens, $1.37. It is made of two parts:
  * the `/compact` summary at 18:36, which the transcript does not log as a
    call;
  * the helper model behind the web search and fetch tools: 61,797 tokens,
    $0.10.

## Caveats

* **"Other" has 0.80 M tokens excluding cache reads.** Most of that is one
  call, sending the schematic PDF at 18:18 after a 5½-hour pause. The prompt
  cache had expired, so the whole conversation, 679 k tokens, was written to
  the cache again.
* **The compaction's own time goes to PCB.** The compaction at 18:36 fell
  inside the PCB work, so its time is credited to the call before it. That
  call is a PCB call at 18:34, which got 126 s.
* **Calls that did several things are assigned by their main purpose.** For
  example:
  * Builds and netlist checks while writing the circuit are Schematic &
    research.
  * Inspecting candidate parts' footprints while choosing parts is Schematic
    & research.
  * Deleting unused part folders before the first commit is Other.

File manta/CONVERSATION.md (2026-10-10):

# Conversation export: Claude Code llm_circuitgen_tests

Claude session on `cHemingway/llm_circuitgen_tests`, branch `solartron-7075-interface`, 2026-10-10 12:20 – 2026-10-10 13:05 UTC.
This export covers every message up to, but not including, the request to export it.

## Totals

| Time | |
|---|---|
| **Active time** (from each user message until the reply finished) | **45.5 min (0 h 46 min)** |
| Tool's own counters: model (API) time + tool time | Not recorded: the transcript has no cost-state record |
| Wall clock, first message to last reply | 0 h 46 min |
| Of which waiting for the user | 0 h 00 min |
| … including stops at a usage limit | 0 h 00 min (none recorded) |

| Tokens | |
|---|---|
| Input, uncached | 382 |
| Input, written to the prompt cache | 548,629 |
| Input, read from the prompt cache | 62,090,289 |
| Output (of which 144,526 thinking) | 244,388 |
| **Total, main model** (claude-opus-5-5, 191 API responses) | **62,883,688** |
| Helper models (web tools: 1 WebFetch, 2 WebSearch) | Not recorded in the transcript |
| **Grand total** (main model only) | **62,883,688** |
| API-equivalent cost reported by the tool | Not recorded: the transcript has no cost-state record |

Claude Code kept no "cost-state" record in this session's transcript
(`~/.claude/projects/-home-chris-llm-circuitgen-tests/<session-id>.jsonl`), so the tool's own
API time, tool time and cost are left out rather than estimated. The token rows are the sums of the
`usage` field the transcript records on each of the 191 API responses (counted once per
response; a response written as several records repeats the same usage). The helper models behind
WebFetch and WebSearch report no usage there, so their tokens are not included. Active time runs from
the one user message (12:20:13 UTC) to the last assistant record before the export request
(13:05:46 UTC), from the records' own timestamps. Every tool call was approved automatically
by the session's permission configuration, so there were no permission prompts, and there were no
usage-limit stops.

### Notes on this export

* Each tool call is folded into a collapsible block. Inputs are cut at 1500 characters and outputs at 800; images show as `[image]`.
* Hidden reasoning, system reminders and background-task notifications are not included.
* The scratchpad path is shortened to `$SCRATCH` (its parent session directory to `$SCRATCH/..`), and email addresses are redacted.

---

# Conversation

## User (2026-10-10 12:20 UTC)

Use manta to design me a RP2354A powered Solartron 7075 multimeter interface, using the 50 way D connector on the Solartron. Put it in the folder manta. Do these changes on a new branch.

Manta is https://github.com/Derrick-Derrickson/Manta which you can find installed as "manta"

DO NOT LOOK AT OTHER BRANCHES FOR CODE, RELY ON THE TOOL, THE DATASHEET, AND WHAT YOU CAN FIND ONLINE ONLY, DON'T COPY THE OUTPUTS OF OTHER TOOLS USED IN THIS BENCHMARK.

In the top level folder inputs is a datasheet for the multimeter. It describes how the interface works in section 9.

Signals to/from the multimeter should be opto-isolated to prevent USB ground noise from affecting the system. I was thinking therefore they should be done through shift registers to minimise the number of signals across the isolation barrier.

Select parts from manta's library, then LCSC where possible.

Have the board sit flat on the back of the multimeter, using a vertical PCB mount D-Sub connector on one side and a vertical USB-B connector on the other side of the board.

The board will be rectangular, and mechanically fixed to the solartron using the jackscrews on the D-Sub connector, so doesn't need any other mounting holes.

## Claude (12:20 UTC)

I'll start by exploring the repo, the datasheet, and the Manta tool.

<details><summary>🔧 Bash: List repo contents and check manta tool</summary>

```bash
ls -la && ls -la inputs && git branch -a && which manta && manta --help 2>&1 | head -50
```

result:
```
total 16
drwxr-xr-x  4 chris chris 4096 Oct 10 12:53 .
drwx------ 18 chris chris 4096 Oct 10 13:20 ..
drwxr-xr-x  8 chris chris 4096 Oct 10 12:53 .git
drwxr-xr-x  2 chris chris 4096 Oct 10 12:53 inputs
total 14324
drwxr-xr-x 2 chris chris     4096 Oct 10 12:53 .
drwxr-xr-x 4 chris chris     4096 Oct 10 12:53 ..
-rw-r--r-- 1 chris chris 14658880 Oct 10 12:53 solartron_7075_service_manual.pdf
  main
* start
  remotes/origin/HEAD -> origin/main
  remotes/origin/claude/blissful-carson-o7dlwb
  remotes/origin/claude/dazzling-mendel-wb2g7k
  remotes/origin/claude/modest-edison-n10mty
  remotes/origin/claude/peaceful-thompson-hefobu
  remotes/origin/main
  remotes/origin/skidl
  remotes/origin/start
/home/chris/.local/bin/manta
manta -- the Manta Schematic Definition Language compiler.

Usage: ma… [514 more characters truncated]
```
</details>

## Claude (12:20 UTC)

Creating the new branch first, then digging into Manta's install for docs and the part library.

<details><summary>🔧 Bash: Create new branch and inspect manta binary</summary>

```bash
git checkout -b solartron-7075-interface && cat /home/chris/.local/bin/manta | head -30; file /home/chris/.local/bin/manta; ls -la /home/chris/.local/bin/
```

result:
```
<persisted-output>
Output too large (29.6KB). Full output saved to: /home/chris/.claude/projects/-home-chris-llm-circuitgen-tests/206dd941-0f66-4a96-8194-cd705ac2e282/tool-results/bq2qv470a.txt

Preview (first 2KB):
Switched to a new branch 'solartron-7075-interface'
�ELF��������������>�������������@��������)����������@�8���@�,�*���������@�������@�������@�������������������������������������������������������������������������������������������������������������������������������������������������������������������������������0b������0b�����������������������#�������C�������C�������e������ l����������������������������������������������������[�����������������������#�������3�������3��������������������������������������������������������������������������������������R�td�����#�������C�����… [913 more characters truncated]
```
</details>

<details><summary>🔧 Bash: Find manta installation files and library</summary>

```bash
ls -la /home/chris/.local/bin/ | head -50; ls -la /home/chris/.local/share/ 2>/dev/null; ls -la ~/.manta ~/.config/manta 2>/dev/null; find / -iname "*manta*" -not -path "/proc/*" -not -path "/sys/*" 2>/dev/null | grep -v llm_circuitgen_tests | head -50
```

result:
```
Command did not complete within its 120s timeout and was moved to the background (ID: bbq615spa). Output is being written to: $SCRATCH/../tasks/bbq615spa.output. You will be notified when it completes. To check interim output, use Read on that file path.
```
</details>

<details><summary>🔧 Bash: Read interim output of find</summary>

```bash
cat $SCRATCH/../tasks/bbq615spa.output
```

result:
```
total 89580
drwxr-xr-x 2 chris chris     4096 Oct 10 12:52 .
drwxr-xr-x 5 chris chris     4096 Jul 18 09:15 ..
lrwxrwxrwx 1 chris chris       48 Jul 18 09:15 claude -> /home/chris/.local/share/claude/versions/2.1.214
-rw-r--r-- 1 chris chris      328 Jul 12  2025 env
-rw-r--r-- 1 chris chris      165 Jul 12  2025 env.fish
lrwxrwxrwx 1 chris chris       56 Jul 27  2025 hf -> /home/chris/.local/share/uv/tools/huggingface-hub/bin/hf
lrwxrwxrwx 1 chris chris       69 Jul 27  2025 huggingface-cli -> /home/chris/.local/share/uv/tools/huggingface-hub/bin/huggingface-cli
-rwxr-xr-x 1 chris chris 46150848 Oct 10 12:42 manta
lrwxrwxrwx 1 chris chris       65 Jul 27  2025 tiny-agents -> /home/chris/.local/share/uv/tools/huggingface-hub/bin/tiny-agents
-rwxr-xr-x 1 chris chris 45184016 Jul  9  2025 uv… [3380 more characters truncated]
```
</details>

## Claude (12:22 UTC)

Manta's source is at `/home/chris/manta`. Let me stop the slow search and look at the docs and agent skills there.

<details><summary>🔧 TaskStop</summary>

```json
{
  "task_id": "bbq615spa"
}
```

result:
```
{"message":"Successfully stopped task: bbq615spa (ls -la /home/chris/.local/bin/ | head -50; ls -la /home/chris/.local/share/ 2>/dev/null; ls -la ~/.manta ~/.config/manta 2>/dev/null; find / -iname \"*manta*\" -not -path \"/proc/*\" -not -path \"/sys/*\" 2>/dev/null | grep -v llm_circuitgen_tests | head -50)","task_id":"bbq615spa","task_type":"local_bash","command":"ls -la /home/chris/.local/bin/ | head -50; ls -la /home/chris/.local/share/ 2>/dev/null; ls -la ~/.manta ~/.config/manta 2>/dev/null; find / -iname \"*manta*\" -not -path \"/proc/*\" -not -path \"/sys/*\" 2>/dev/null | grep -v llm_circuitgen_tests | head -50"}
```
</details>

<details><summary>🔧 Bash: Show manta repo layout</summary>

```bash
cd /home/chris/manta && ls -la && git log --oneline | head -5 && find . -path ./build -prune -o -type f -print | grep -v "^./.git/" | grep -v "/src/" | grep -v "/tests/" | head -100
```

result:
```
total 148
drwxr-xr-x 13 chris chris  4096 Oct 10 12:40 .
drwx------ 18 chris chris  4096 Oct 10 13:20 ..
drwxr-xr-x  3 chris chris  4096 Oct 10 12:40 agents
-rw-r--r--  1 chris chris  3627 Oct 10 12:40 AGENTS.md
drwxr-xr-x  4 chris chris  4096 Oct 10 12:50 build
-rw-r--r--  1 chris chris 31823 Oct 10 12:40 CHANGELOG.md
drwxr-xr-x  2 chris chris  4096 Oct 10 12:40 cmake
-rw-r--r--  1 chris chris  3089 Oct 10 12:40 CMakeLists.txt
-rw-r--r--  1 chris chris  2570 Oct 10 12:40 CMakePresets.json
drwxr-xr-x  2 chris chris  4096 Oct 10 12:40 docs
drwxr-xr-x  3 chris chris  4096 Oct 10 12:40 examples
drwxr-xr-x  2 chris chris  4096 Oct 10 12:40 example_schematics
drwxr-xr-x  8 chris chris  4096 Oct 10 12:40 .git
-rw-r--r--  1 chris chris    59 Oct 10 12:40 .gitignore
-rw-r--r--  1 chris chris 35149… [2149 more characters truncated]
```
</details>

<details><summary>🔧 Bash: Read manta README and agent docs</summary>

```bash
cd /home/chris/manta && cat README.md AGENTS.md agents/README.md examples/README.md
```

result:
````
# manta

A compiler for the Manta Schematic Definition Language, specification revision 2.0.

Manta is a plain-text language for describing electronic schematics: the
components on one printed circuit board, their interconnections, the electrical
constraints on those interconnections, and the looms that plug into it.

```
block power-and-signal {
    GND &TYPE=GROUND;
    >nPWR-EN;

    SW = SW-NODE
        = (.{L?~MT100UFA}.)+2
        = ({C?~100nF-0603: .=GND}.)*4
       == 3V3
        = S.{Q?~FFET123: .G=nPWR-EN; }.D
        = PWR-SWITCHED
        &CURRENT=3A &!VOLTAGE=6V;
};
```

## Building

Needs a C++23 compiler and CMake 3.24 or later. No third-party dependencies.

```sh
cmake --preset linux-release
cmake --build --preset linux-release -j
ctest --preset linux-release
```

Cross-com… [20935 more characters truncated]
````
</details>

## Claude (12:22 UTC)

Now the skills — these are the core instructions for writing designs and parts.

<details><summary>🔧 Bash: Read design and parts skills</summary>

```bash
cd /home/chris/manta && cat agents/skills/writing-manta-designs/SKILL.md agents/skills/writing-manta-parts/SKILL.md
```

result:
````
---
name: writing-manta-designs
description: Write or modify a manta schematic — a board, a block, a cable, the nets and constraints between parts. Use when asked to describe a circuit in manta, add a subcircuit, or fix diagnostics from a manta build. Covers the house style, the connection operators, and the checks that judge the result.
---

# Writing manta designs

A design is a set of named declarations describing one board. Order never
matters; a name may be used before it is declared. The compiler is the oracle:
a design is finished when this is silent, and not before.

```sh
manta fmt --check src/*.manta
manta compile -o build/ src/*.manta
manta check --top <block> -L build/ --rules <project>.mantaRules -Werror
```

## Work in this order

1. **Parts first.** Find or write every part … [14207 more characters truncated]
````
</details>

<details><summary>🔧 Bash: Search for a parts library in manta</summary>

```bash
cd /home/chris/manta && grep -ril "library" --include=*.md . | grep -v build | head; ls src; ls -R src | grep -i -E "lib|part" | head; ls /home/chris/.local/share/manta -R
```

result:
```
README.md
agents/README.md
CHANGELOG.md
agents/skills/writing-manta-parts/SKILL.md
agents/skills/writing-manta-rules/SKILL.md
agents/skills/writing-manta-designs/references/checklist.md
agents/skills/writing-manta-designs/references/diagnostics.md
agents/skills/extending-the-compiler/SKILL.md
docs/assumptions.md
docs/spec.md
AGENTS.md
ast
base
cli
diag
erc
export
fmt
json
lex
link
main.cpp
obj
parse
README.md
render
rules
sema
source
part_info.cpp
part_info.h
/home/chris/.local/share/manta:
schema

/home/chris/.local/share/manta/schema:
mantaNets.schema.json
mantaO.schema.json
README.md
Shell cwd was reset to /home/chris/llm_circuitgen_tests
```
</details>

## Claude (12:22 UTC)

No standalone library is installed — the parts that ship with Manta are in `examples/blinky`. Let me read that whole example, since it's both the library and the style reference.

<details><summary>🔧 Bash: Read blinky types and parts library</summary>

```bash
cd /home/chris/manta/examples/blinky && wc -l * && cat types.manta parts.manta
```

result:
```
   27 blinky.fpmap
  119 blinky.mantaRules
  186 board.manta
   66 esd.manta
   69 ldo.manta
   29 leads.manta
  121 mcu.manta
  337 parts.manta
   26 types.manta
  980 total
// Types shared by the board: bus and pair harnesses, net classes, and the
// delay-matching group for the USB pair.

harness i2c-bus {
    SDA<> &TYPE=OPENDRAIN;
    SCL<> &TYPE=OPENDRAIN;
};

// USB 2.0 full speed: a 90 ohm differential pair, matched within the
// tolerance the USB specification allows for a device-side trace.
harness usb2 {
    &HARNESS=diff;             // this type is a pair: members '+' and '-'
    &!IMP     = 90RD;
    &MAXDELAY = 600ps;
};

netclass power {
    &CURRENT  = 1A;
    &!VOLTAGE = 6V;
};

match usb-pair {
    @src       = U2;
    @dest      = [J1];
    @tolerance = 100ps;
};
// Par… [8990 more characters truncated]
```
</details>

<details><summary>🔧 Bash: Read blinky board, LDO and ESD files</summary>

```bash
cd /home/chris/manta/examples/blinky && cat board.manta ldo.manta esd.manta
```

result:
```
// blinky -- a USB-powered indicator board.
//
// USB-C in, a 3V3 LDO, an STM32F042 with USB and I2C, two indicator LEDs, a
// bicolour status LED, two configuration switches, a VBUS sense divider and
// an SWD debug header. It passes every check with nothing to report, and it
// uses every construct the language has, so it doubles as a tour.

// An indicator: a series resistor and an LED to ground. The resistor value
// is a parameter so the same block serves LEDs of different brightness.
block indicator {
    @VERSION    = 1.4+;
    @FLATFORMAT = "$INSTANCE$_$COMPONENT$";
    #~series-r  = 1;

    >DRIVE;
    >>GND;

    DRIVE = .{R1~R-$"series-r"$kR-0603}. = LED-ANODE = A.{D1~LED-0603}.K = GND;
    LED-ANODE &RENDER=WIRE;
};

// A bare copper pad for a probe. Private to this board, and … [9596 more characters truncated]
```
</details>

<details><summary>🔧 Bash: Read blinky MCU, leads, fpmap and rules</summary>

```bash
cd /home/chris/manta/examples/blinky && cat mcu.manta leads.manta blinky.fpmap blinky.mantaRules
```

result:
```
// Pins are named as the datasheet names them; a pin's alternate functions
// are noted on its line and which one a board uses is the board's decision.
part MCU-STM32F042 {
    @VERSION       = 2.0+;
    @~footprint    = TSSOP-20;
    #value         = STM32F042F6P6;
    @!type         = mcu;
    #~mpn          = "STM32F042F6P6";
    #!manufacturer = "STMicroelectronics";
    >#~source      = digikey;

    1       : BOOT0<;
    2       : PF0<>;                    // I2C1_SDA (AF1), OSC_IN
    3       : PF1<>;                    // I2C1_SCL (AF1), OSC_OUT
    4       : NRST<;                    // internal 40k pull-up, filtered
    5       : VDDA<  &TYPE=POWER;
    [6:13]  : PA[0:7]<> #VOH=2V9 #VOL=0V4 #VIH=2V31 #VIL=0V99;   // ADC_IN0..7
    14      : PB1<>  #VOH=2V9 #VOL=0V4 #VIH=2V31 #VIL… [12493 more characters truncated]
```
</details>

<details><summary>🔧 Bash: Read manta idioms and checklist references</summary>

```bash
cd /home/chris/manta/agents/skills/writing-manta-designs/references && cat idioms.md checklist.md
```

result:
````
# Idioms

Patterns that come up on every board, written in the house style: passive
networks as chains, large ICs as binding blocks, comments about the circuit.

## Decoupling

A shunt has no far side, so `==` continues past it. One rail, one chain:

```
3V3 = .{C1~C-10uF-0805: .=GND} == .{C2~C-100nF-0603: .=GND} == .{C3~C-100nF-0603: .=GND};
```

Several identical caps on one node are a multiplicity group, annotated with
a range designator; `*N` hangs copies off the node and each copy's far pin is
settled by its own binding, per copy if they differ:

```
3V3 = ({C%[4:6]~C-100nF-0603: .=GND}.)*3;
3V3 = ({C%[7:8]~C-100nF-0603: .=%[GND,AGND]}.)*2;
```

## Pull-ups, pull-downs, RC at a pin

```
3V3 = .{R3~R-10kR-0603}. = nRESET = .{C4~C-100nF-0603: .=GND};
BOOT0 = .{R9~R-10kR-0603}. = GND;
``… [8866 more characters truncated]
````
</details>

## Claude (12:22 UTC)

Now the language reference and diagnostics, then the datasheet.

<details><summary>🔧 Bash: Read manta language reference</summary>

```bash
cd /home/chris/manta/agents/skills && wc -l writing-manta-designs/references/* writing-manta-rules/SKILL.md ../../docs/*.md && cat writing-manta-designs/references/language-reference.md
```

result:
```
    74 writing-manta-designs/references/checklist.md
   270 writing-manta-designs/references/diagnostics.md
   206 writing-manta-designs/references/idioms.md
   215 writing-manta-designs/references/language-reference.md
   156 writing-manta-rules/SKILL.md
   596 ../../docs/assumptions.md
    33 ../../docs/README.md
   223 ../../docs/rules.md
  3124 ../../docs/spec.md
  4897 total
# Language reference, condensed

The full specification is `docs/spec.md` and is the authority. This is a working
summary for quick recall; go to the specification for anything subtle.
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

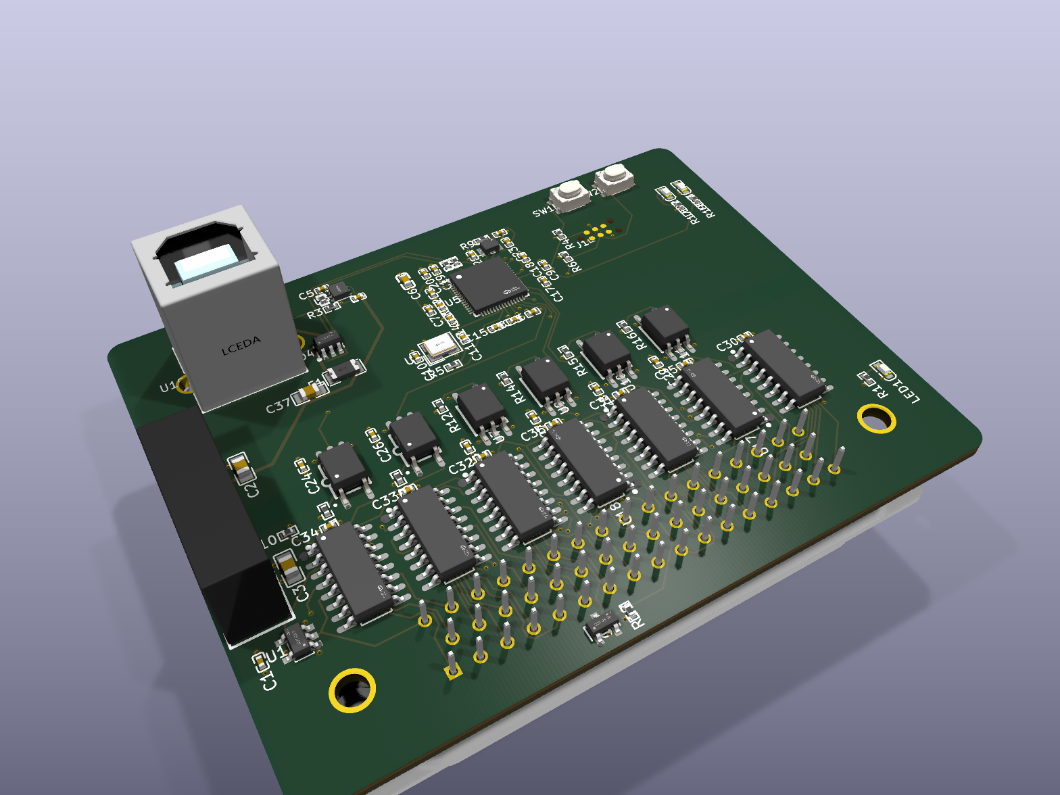
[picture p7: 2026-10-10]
atopile/fab/renders/iso.png

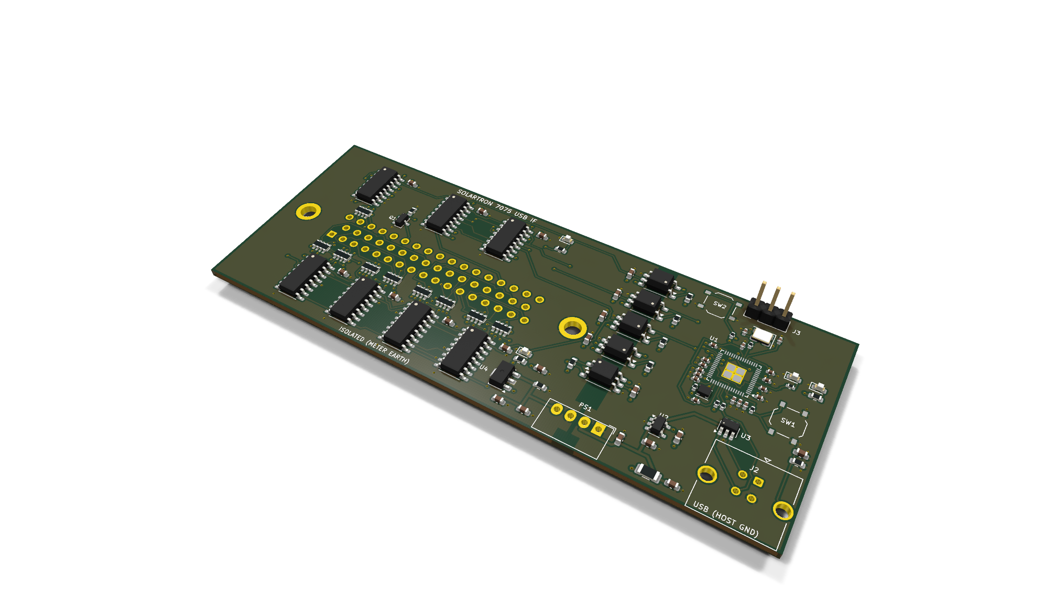
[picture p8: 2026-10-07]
skidl/pcb/render/iso.png

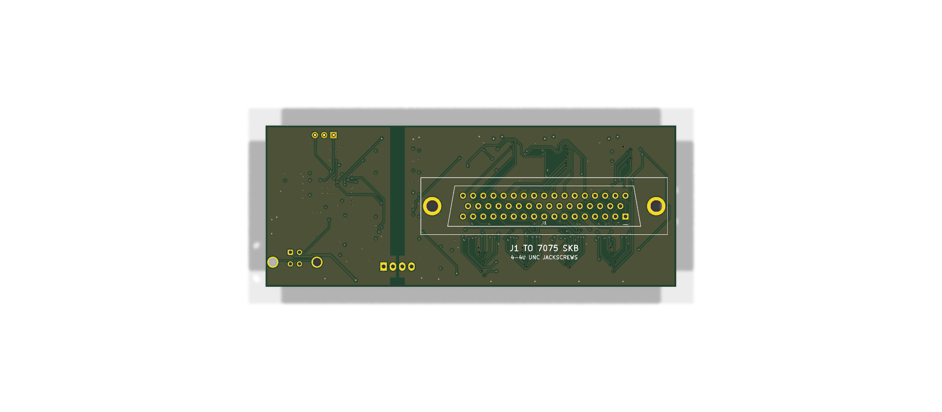
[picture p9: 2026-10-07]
skidl/pcb/render/bottom.png

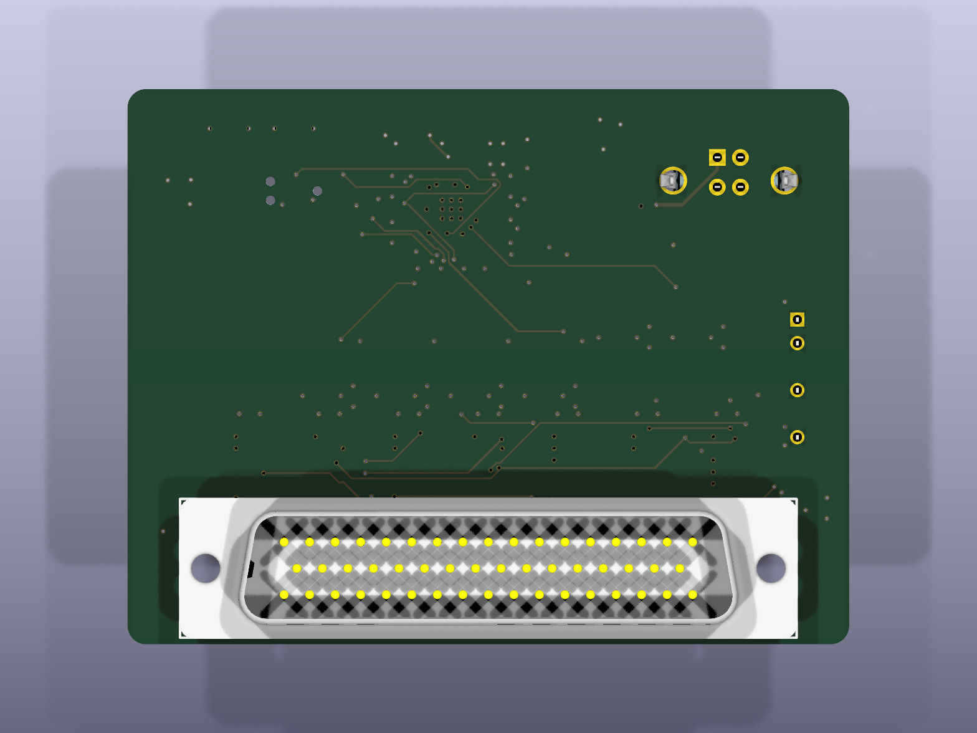
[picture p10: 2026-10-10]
atopile/fab/renders/bottom.png

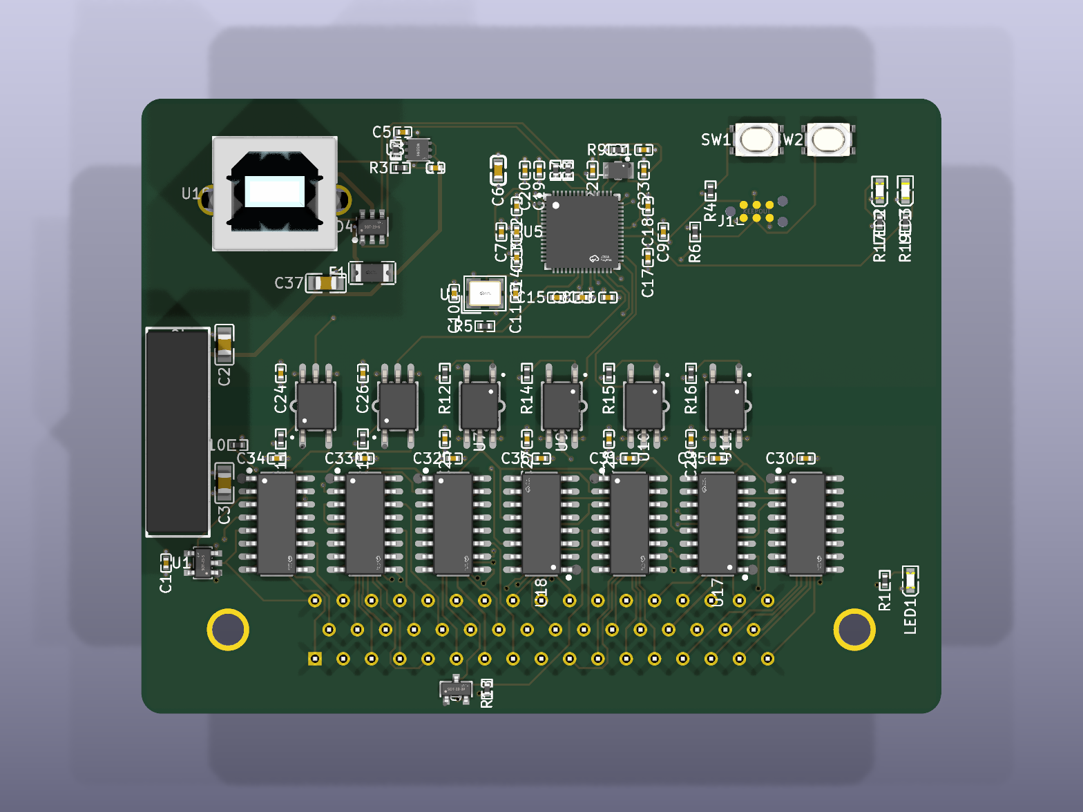
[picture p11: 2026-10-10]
atopile/fab/renders/top.png

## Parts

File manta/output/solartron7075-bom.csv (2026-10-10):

designator | part | type | footprint | fitted | quantity | description | board-rev | value | mpn | manufacturer | lcsc | mount | tolerance | power | voltage | dielectric | current | vf | hardware
J2 | USB-B-VERT | boardconnector | USB-B-TE-5787834 | TRUE | 1 | Opto-isolated USB interface for the Solartron 7075 50-way BCD port | A | USB-B vertical | 5787834-1 | TE Connectivity | C592900 | top side, vertical
U2 | USBLC6-2SC6 | esd | SOT-23-6 | TRUE | 1 | Opto-isolated USB interface for the Solartron 7075 50-way BCD port | A | USBLC6-2SC6 | USBLC6-2SC6 | STMicroelectronics | C7519
R1 | R-27R-0603 | resistor | R-0603 | TRUE | 1 | Opto-isolated USB interface for the Solartron 7075 50-way BCD port | A | 27R | RC0603FR-0727RL |  | C137753 |  | ±1% | 100mW
R2 | R-27R-0603 | resistor | R-0603 | TRUE | 1 | Opto-isolated USB interface for the Solartron 7075 50-way BCD port | A | 27R | RC0603FR-0727RL |  | C137753 |  | ±1% | 100mW
C1 | C-1uF-0603 | capacitor | C-0603 | TRUE | 1 | Opto-isolated USB interface for the Solartron 7075 50-way BCD port | A | 1uF | CL10B105KA8NNNC |  | C29936 |  |  |  | 25V | X7R
C2 | C-100nF-0603 | capacitor | C-0603 | TRUE | 1 | Opto-isolated USB interface for the Solartron 7075 50-way BCD port | A | 100nF | CC0603KRX7R9BB104 |  | C14663 |  |  |  | 50V | X7R
U3 | LDO-3V3 | regulator | SOT-23-5 | TRUE | 1 | Opto-isolated USB interface for the Solartron 7075 50-way BCD port | A | AP2112K-3.3 | AP2112K-3.3TRG1 | Diodes Incorporated | C51118
C3 | C-1uF-0603 | capacitor | C-0603 | TRUE | 1 | Opto-isolated USB interface for the Solartron 7075 50-way BCD port | A | 1uF | CL10B105KA8NNNC |  | C29936 |  |  |  | 25V | X7R
C4 | C-10uF-0805 | capacitor | C-0805 | TRUE | 1 | Opto-isolated USB interface for the Solartron 7075 50-way BCD port | A | 10uF | CL21A106KAYNNNE |  | C15850 |  |  |  | 25V | X5R
U1 | RP2354A | mcu | QFN-60-7x7 | TRUE | 1 | Opto-isolated USB interface for the Solartron 7075 50-way BCD port | A | RP2354A | RP2354A | Raspberry Pi | C41378174
R4 | R-1kR-0603 | resistor | R-0603 | TRUE | 1 | Opto-isolated USB interface for the Solartron 7075 50-way BCD port | A | 1kR | RC0603FR-071KL |  | C22548 |  | ±1% | 100mW
C23 | C-4u7F-0402 | capacitor | C-0402 | TRUE | 1 | Opto-isolated USB interface for the Solartron 7075 50-way BCD port | A | 4u7F | CL05A475MP5NRNC |  | C23733 |  | ±20% |  | 10V | X5R
C16 | C-100nF-0603 | capacitor | C-0603 | TRUE | 1 | Opto-isolated USB interface for the Solartron 7075 50-way BCD port | A | 100nF | CC0603KRX7R9BB104 |  | C14663 |  |  |  | 50V | X7R
C24 | C-4u7F-0402 | capacitor | C-0402 | TRUE | 1 | Opto-isolated USB interface for the Solartron 7075 50-way BCD port | A | 4u7F | CL05A475MP5NRNC |  | C23733 |  | ±20% |  | 10V | X5R
R3 | R-33R-0603 | resistor | R-0603 | TRUE | 1 | Opto-isolated USB interface for the Solartron 7075 50-way BCD port | A | 33R | RC0603FR-0733RL |  | C108661 |  | ±1% | 100mW
L1 | L-3u3H-AOTA | inductor | L-2016-AOTA | TRUE | 1 | Opto-isolated USB interface for the Solartron 7075 50-way BCD port | A | 3u3H | AOTA-B201610S3R3-101-T | Abracon | C42411119
C22 | C-4u7F-0402 | capacitor | C-0402 | TRUE | 1 | Opto-isolated USB interface for the Solartron 7075 50-way BCD port | A | 4u7F | CL05A475MP5NRNC |  | C23733 |  | ±20% |  | 10V | X5R
C21 | C-4u7F-0402 | capacitor | C-0402 | TRUE | 1 | Opto-isolated USB interface for the Solartron 7075 50-way BCD port | A | 4u7F | CL05A475MP5NRNC |  | C23733 |  | ±20% |  | 10V | X5R
C17 | C-100nF-0603 | capacitor | C-0603 | TRUE | 1 | Opto-isolated USB interface for the Solartron 7075 50-way BCD port | A | 100nF | CC0603KRX7R9BB104 |  | C14663 |  |  |  | 50V | X7R
R5 | R-1kR-0603 | resistor | R-0603 | TRUE | 1 | Opto-isolated USB interface for the Solartron 7075 50-way BCD port | A | 1kR | RC0603FR-071KL |  | C22548 |  | ±1% | 100mW
SW1 | SW-TACT-5x5 | switch | SW-TS-1187A | TRUE | 1 | Opto-isolated USB interface for the Solartron 7075 50-way BCD port | A | tact 5.1x5.1 | TS-1187A-B-A-B | XKB | C318884
C10 | C-100nF-0603 | capacitor | C-0603 | TRUE | 1 | Opto-isolated USB interface for the Solartron 7075 50-way BCD port | A | 100nF | CC0603KRX7R9BB104 |  | C14663 |  |  |  | 50V | X7R
C11 | C-100nF-0603 | capacitor | C-0603 | TRUE | 1 | Opto-isolated USB interface for the Solartron 7075 50-way BCD port | A | 100nF | CC0603KRX7R9BB104 |  | C14663 |  |  |  | 50V | X7R
C12 | C-100nF-0603 | capacitor | C-0603 | TRUE | 1 | Opto-isolated USB interface for the Solartron 7075 50-way BCD port | A | 100nF | CC0603KRX7R9BB104 |  | C14663 |  |  |  | 50V | X7R
C13 | C-100nF-0603 | capacitor | C-0603 | TRUE | 1 | Opto-isolated USB interface for the Solartron 7075 50-way BCD port | A | 100nF | CC0603KRX7R9BB104 |  | C14663 |  |  |  | 50V | X7R
C14 | C-100nF-0603 | capacitor | C-0603 | TRUE | 1 | Opto-isolated USB interface for the Solartron 7075 50-way BCD port | A | 100nF | CC0603KRX7R9BB104 |  | C14663 |  |  |  | 50V | X7R
C15 | C-100nF-0603 | capacitor | C-0603 | TRUE | 1 | Opto-isolated USB interface for the Solartron 7075 50-way BCD port | A | 100nF | CC0603KRX7R9BB104 |  | C14663 |  |  |  | 50V | X7R
C18 | C-100nF-0603 | capacitor | C-0603 | TRUE | 1 | Opto-isolated USB interface for the Solartron 7075 50-way BCD port | A | 100nF | CC0603KRX7R9BB104 |  | C14663 |  |  |  | 50V | X7R
C19 | C-100nF-0603 | capacitor | C-0603 | TRUE | 1 | Opto-isolated USB interface for the Solartron 7075 50-way BCD port | A | 100nF | CC0603KRX7R9BB104 |  | C14663 |  |  |  | 50V | X7R
C20 | C-100nF-0603 | capacitor | C-0603 | TRUE | 1 | Opto-isolated USB interface for the Solartron 7075 50-way BCD port | A | 100nF | CC0603KRX7R9BB104 |  | C14663 |  |  |  | 50V | X7R
C25 | C-15pF-0603 | capacitor | C-0603 | TRUE | 1 | Opto-isolated USB interface for the Solartron 7075 50-way BCD port | A | 15pF | CL10C150JB8NNNC |  | C1644 |  | ±5% |  | 50V | C0G
Y1 | ABM8-272-T3 | crystal | XTAL-3225-4 | TRUE | 1 | Opto-isolated USB interface for the Solartron 7075 50-way BCD port | A | 12MHz | ABM8-272-T3 | Abracon | C20625731
C26 | C-15pF-0603 | capacitor | C-0603 | TRUE | 1 | Opto-isolated USB interface for the Solartron 7075 50-way BCD port | A | 15pF | CL10C150JB8NNNC |  | C1644 |  | ±5% |  | 50V | C0G
R7 | R-10kR-0603 | resistor | R-0603 | TRUE | 1 | Opto-isolated USB interface for the Solartron 7075 50-way BCD port | A | 10kR | RC0603FR-0710KL |  | C98220 |  | ±1% | 100mW
SW2 | SW-TACT-5x5 | switch | SW-TS-1187A | TRUE | 1 | Opto-isolated USB interface for the Solartron 7075 50-way BCD port | A | tact 5.1x5.1 | TS-1187A-B-A-B | XKB | C318884
R6 | R-1kR-0603 | resistor | R-0603 | TRUE | 1 | Opto-isolated USB interface for the Solartron 7075 50-way BCD port | A | 1kR | RC0603FR-071KL |  | C22548 |  | ±1% | 100mW
J3 | JST-SH-3-SIDE | boardconnector | JST-SH-3-SIDE | TRUE | 1 | Opto-isolated USB interface for the Solartron 7075 50-way BCD port | A | JST SH 1x3 | SM03B-SRSS-TB(LF)(SN) | JST | C160403
R8 | R-470R-0603 | resistor | R-0603 | TRUE | 1 | Opto-isolated USB interface for the Solartron 7075 50-way BCD port | A | 470R | RC0603FR-07470RL |  | C114669 |  | ±1% | 100mW
D1 | LED-0603 | led | LED-0603 | TRUE | 1 | Opto-isolated USB interface for the Solartron 7075 50-way BCD port | A | green | LTST-C191KGKT |  | C125098 |  |  |  |  |  | 5mA | 2V4
FB1 | FB-600R-0603 | ferrite | L-0603 | TRUE | 1 | Opto-isolated USB interface for the Solartron 7075 50-way BCD port | A | 600R@100MHz | BLM18KG601SN1D | Murata | C85833
C40 | C-10uF-0805 | capacitor | C-0805 | TRUE | 1 | Opto-isolated USB interface for the Solartron 7075 50-way BCD port | A | 10uF | CL21A106KAYNNNE |  | C15850 |  |  |  | 25V | X5R
PS1 | B0509S-1WR3 | isolated-dcdc | SIP-4-DCDC-1W | TRUE | 1 | Opto-isolated USB interface for the Solartron 7075 50-way BCD port | A | B0509S-1WR3 | B0509S-1WR3 | YLPTEC | C5369463
C41 | C-10uF-0805 | capacitor | C-0805 | TRUE | 1 | Opto-isolated USB interface for the Solartron 7075 50-way BCD port | A | 10uF | CL21A106KAYNNNE |  | C15850 |  |  |  | 25V | X5R
U4 | HT7550-1 | regulator | SOT-89-3 | TRUE | 1 | Opto-isolated USB interface for the Solartron 7075 50-way BCD port | A | HT7550-1 | HT7550-1 | UMW | C347189
C42 | C-10uF-0805 | capacitor | C-0805 | TRUE | 1 | Opto-isolated USB interface for the Solartron 7075 50-way BCD port | A | 10uF | CL21A106KAYNNNE |  | C15850 |  |  |  | 25V | X5R
C43 | C-100nF-0603 | capacitor | C-0603 | TRUE | 1 | Opto-isolated USB interface for the Solartron 7075 50-way BCD port | A | 100nF | CC0603KRX7R9BB104 |  | C14663 |  |  |  | 50V | X7R
R15 | R-1kR-0603 | resistor | R-0603 | TRUE | 1 | Opto-isolated USB interface for the Solartron 7075 50-way BCD port | A | 1kR | RC0603FR-071KL |  | C22548 |  | ±1% | 100mW
R16 | R-1kR-0603 | resistor | R-0603 | TRUE | 1 | Opto-isolated USB interface for the Solartron 7075 50-way BCD port | A | 1kR | RC0603FR-071KL |  | C22548 |  | ±1% | 100mW
R17 | R-470R-0603 | resistor | R-0603 | TRUE | 1 | Opto-isolated USB interface for the Solartron 7075 50-way BCD port | A | 470R | RC0603FR-07470RL |  | C114669 |  | ±1% | 100mW
D2 | LED-0603 | led | LED-0603 | TRUE | 1 | Opto-isolated USB interface for the Solartron 7075 50-way BCD port | A | green | LTST-C191KGKT |  | C125098 |  |  |  |  |  | 5mA | 2V4
R10 | R-470R-0603 | resistor | R-0603 | TRUE | 1 | Opto-isolated USB interface for the Solartron 7075 50-way BCD port | A | 470R | RC0603FR-07470RL |  | C114669 |  | ±1% | 100mW
U10 | TLP2361 | optocoupler | SO-5-6-TOSHIBA | TRUE | 1 | Opto-isolated USB interface for the Solartron 7075 50-way BCD port | A | TLP2361 | TLP2361(TPL,E | Toshiba | C107626
R11 | R-470R-0603 | resistor | R-0603 | TRUE | 1 | Opto-isolated USB interface for the Solartron 7075 50-way BCD port | A | 470R | RC0603FR-07470RL |  | C114669 |  | ±1% | 100mW
U11 | TLP2361 | optocoupler | SO-5-6-TOSHIBA | TRUE | 1 | Opto-isolated USB interface for the Solartron 7075 50-way BCD port | A | TLP2361 | TLP2361(TPL,E | Toshiba | C107626
R12 | R-470R-0603 | resistor | R-0603 | TRUE | 1 | Opto-isolated USB interface for the Solartron 7075 50-way BCD port | A | 470R | RC0603FR-07470RL |  | C114669 |  | ±1% | 100mW
U12 | TLP2361 | optocoupler | SO-5-6-TOSHIBA | TRUE | 1 | Opto-isolated USB interface for the Solartron 7075 50-way BCD port | A | TLP2361 | TLP2361(TPL,E | Toshiba | C107626
R13 | R-470R-0603 | resistor | R-0603 | TRUE | 1 | Opto-isolated USB interface for the Solartron 7075 50-way BCD port | A | 470R | RC0603FR-07470RL |  | C114669 |  | ±1% | 100mW
U13 | TLP2361 | optocoupler | SO-5-6-TOSHIBA | TRUE | 1 | Opto-isolated USB interface for the Solartron 7075 50-way BCD port | A | TLP2361 | TLP2361(TPL,E | Toshiba | C107626
C30 | C-100nF-0603 | capacitor | C-0603 | TRUE | 1 | Opto-isolated USB interface for the Solartron 7075 50-way BCD port | A | 100nF | CC0603KRX7R9BB104 |  | C14663 |  |  |  | 50V | X7R
C31 | C-100nF-0603 | capacitor | C-0603 | TRUE | 1 | Opto-isolated USB interface for the Solartron 7075 50-way BCD port | A | 100nF | CC0603KRX7R9BB104 |  | C14663 |  |  |  | 50V | X7R
C32 | C-100nF-0603 | capacitor | C-0603 | TRUE | 1 | Opto-isolated USB interface for the Solartron 7075 50-way BCD port | A | 100nF | CC0603KRX7R9BB104 |  | C14663 |  |  |  | 50V | X7R
C33 | C-100nF-0603 | capacitor | C-0603 | TRUE | 1 | Opto-isolated USB interface for the Solartron 7075 50-way BCD port | A | 100nF | CC0603KRX7R9BB104 |  | C14663 |  |  |  | 50V | X7R
R14 | R-820R-0603 | resistor | R-0603 | TRUE | 1 | Opto-isolated USB interface for the Solartron 7075 50-way BCD port | A | 820R | RC0603FR-07820RL |  | C114638 |  | ±1% | 100mW
U14 | TLP2361 | optocoupler | SO-5-6-TOSHIBA | TRUE | 1 | Opto-isolated USB interface for the Solartron 7075 50-way BCD port | A | TLP2361 | TLP2361(TPL,E | Toshiba | C107626
C34 | C-100nF-0603 | capacitor | C-0603 | TRUE | 1 | Opto-isolated USB interface for the Solartron 7075 50-way BCD port | A | 100nF | CC0603KRX7R9BB104 |  | C14663 |  |  |  | 50V | X7R
RN10 | RN-100kR-4x0603 | resistor | R-ARRAY-4x0603 | TRUE | 1 | Opto-isolated USB interface for the Solartron 7075 50-way BCD port | A | 4x 100kR | 4D03WGJ0104T5E |  | C1996 |  | ±5% | 62m5W
RN1 | RN-10kR-4x0603 | resistor | R-ARRAY-4x0603 | TRUE | 1 | Opto-isolated USB interface for the Solartron 7075 50-way BCD port | A | 4x 10kR | 4D03WGJ0103T5E |  | C29718 |  | ±5% | 62m5W
RN11 | RN-100kR-4x0603 | resistor | R-ARRAY-4x0603 | TRUE | 1 | Opto-isolated USB interface for the Solartron 7075 50-way BCD port | A | 4x 100kR | 4D03WGJ0104T5E |  | C1996 |  | ±5% | 62m5W
RN2 | RN-10kR-4x0603 | resistor | R-ARRAY-4x0603 | TRUE | 1 | Opto-isolated USB interface for the Solartron 7075 50-way BCD port | A | 4x 10kR | 4D03WGJ0103T5E |  | C29718 |  | ±5% | 62m5W
RN12 | RN-100kR-4x0603 | resistor | R-ARRAY-4x0603 | TRUE | 1 | Opto-isolated USB interface for the Solartron 7075 50-way BCD port | A | 4x 100kR | 4D03WGJ0104T5E |  | C1996 |  | ±5% | 62m5W
RN3 | RN-10kR-4x0603 | resistor | R-ARRAY-4x0603 | TRUE | 1 | Opto-isolated USB interface for the Solartron 7075 50-way BCD port | A | 4x 10kR | 4D03WGJ0103T5E |  | C29718 |  | ±5% | 62m5W
RN13 | RN-100kR-4x0603 | resistor | R-ARRAY-4x0603 | TRUE | 1 | Opto-isolated USB interface for the Solartron 7075 50-way BCD port | A | 4x 100kR | 4D03WGJ0104T5E |  | C1996 |  | ±5% | 62m5W
RN4 | RN-10kR-4x0603 | resistor | R-ARRAY-4x0603 | TRUE | 1 | Opto-isolated USB interface for the Solartron 7075 50-way BCD port | A | 4x 10kR | 4D03WGJ0103T5E |  | C29718 |  | ±5% | 62m5W
RN14 | RN-100kR-4x0603 | resistor | R-ARRAY-4x0603 | TRUE | 1 | Opto-isolated USB interface for the Solartron 7075 50-way BCD port | A | 4x 100kR | 4D03WGJ0104T5E |  | C1996 |  | ±5% | 62m5W
RN5 | RN-10kR-4x0603 | resistor | R-ARRAY-4x0603 | TRUE | 1 | Opto-isolated USB interface for the Solartron 7075 50-way BCD port | A | 4x 10kR | 4D03WGJ0103T5E |  | C29718 |  | ±5% | 62m5W
RN15 | RN-100kR-4x0603 | resistor | R-ARRAY-4x0603 | TRUE | 1 | Opto-isolated USB interface for the Solartron 7075 50-way BCD port | A | 4x 100kR | 4D03WGJ0104T5E |  | C1996 |  | ±5% | 62m5W
RN6 | RN-10kR-4x0603 | resistor | R-ARRAY-4x0603 | TRUE | 1 | Opto-isolated USB interface for the Solartron 7075 50-way BCD port | A | 4x 10kR | 4D03WGJ0103T5E |  | C29718 |  | ±5% | 62m5W
RN16 | RN-100kR-4x0603 | resistor | R-ARRAY-4x0603 | TRUE | 1 | Opto-isolated USB interface for the Solartron 7075 50-way BCD port | A | 4x 100kR | 4D03WGJ0104T5E |  | C1996 |  | ±5% | 62m5W
RN7 | RN-10kR-4x0603 | resistor | R-ARRAY-4x0603 | TRUE | 1 | Opto-isolated USB interface for the Solartron 7075 50-way BCD port | A | 4x 10kR | 4D03WGJ0103T5E |  | C29718 |  | ±5% | 62m5W
RN17 | RN-100kR-4x0603 | resistor | R-ARRAY-4x0603 | TRUE | 1 | Opto-isolated USB interface for the Solartron 7075 50-way BCD port | A | 4x 100kR | 4D03WGJ0104T5E |  | C1996 |  | ±5% | 62m5W
RN8 | RN-10kR-4x0603 | resistor | R-ARRAY-4x0603 | TRUE | 1 | Opto-isolated USB interface for the Solartron 7075 50-way BCD port | A | 4x 10kR | 4D03WGJ0103T5E |  | C29718 |  | ±5% | 62m5W
RN18 | RN-100kR-4x0603 | resistor | R-ARRAY-4x0603 | TRUE | 1 | Opto-isolated USB interface for the Solartron 7075 50-way BCD port | A | 4x 100kR | 4D03WGJ0104T5E |  | C1996 |  | ±5% | 62m5W
RN9 | RN-10kR-4x0603 | resistor | R-ARRAY-4x0603 | TRUE | 1 | Opto-isolated USB interface for the Solartron 7075 50-way BCD port | A | 4x 10kR | 4D03WGJ0103T5E |  | C29718 |  | ±5% | 62m5W
U20 | 74HCT165 | logic | SOIC-16 | TRUE | 1 | Opto-isolated USB interface for the Solartron 7075 50-way BCD port | A | 74HCT165 | CD74HCT165M96 | Texas Instruments | C352828
U21 | 74HCT165 | logic | SOIC-16 | TRUE | 1 | Opto-isolated USB interface for the Solartron 7075 50-way BCD port | A | 74HCT165 | CD74HCT165M96 | Texas Instruments | C352828
U22 | 74HCT165 | logic | SOIC-16 | TRUE | 1 | Opto-isolated USB interface for the Solartron 7075 50-way BCD port | A | 74HCT165 | CD74HCT165M96 | Texas Instruments | C352828
U23 | 74HCT165 | logic | SOIC-16 | TRUE | 1 | Opto-isolated USB interface for the Solartron 7075 50-way BCD port | A | 74HCT165 | CD74HCT165M96 | Texas Instruments | C352828
U24 | 74HCT165 | logic | SOIC-16 | TRUE | 1 | Opto-isolated USB interface for the Solartron 7075 50-way BCD port | A | 74HCT165 | CD74HCT165M96 | Texas Instruments | C352828
C50 | C-100nF-0603 | capacitor | C-0603 | TRUE | 1 | Opto-isolated USB interface for the Solartron 7075 50-way BCD port | A | 100nF | CC0603KRX7R9BB104 |  | C14663 |  |  |  | 50V | X7R
C51 | C-100nF-0603 | capacitor | C-0603 | TRUE | 1 | Opto-isolated USB interface for the Solartron 7075 50-way BCD port | A | 100nF | CC0603KRX7R9BB104 |  | C14663 |  |  |  | 50V | X7R
C52 | C-100nF-0603 | capacitor | C-0603 | TRUE | 1 | Opto-isolated USB interface for the Solartron 7075 50-way BCD port | A | 100nF | CC0603KRX7R9BB104 |  | C14663 |  |  |  | 50V | X7R
C53 | C-100nF-0603 | capacitor | C-0603 | TRUE | 1 | Opto-isolated USB interface for the Solartron 7075 50-way BCD port | A | 100nF | CC0603KRX7R9BB104 |  | C14663 |  |  |  | 50V | X7R
C54 | C-100nF-0603 | capacitor | C-0603 | TRUE | 1 | Opto-isolated USB interface for the Solartron 7075 50-way BCD port | A | 100nF | CC0603KRX7R9BB104 |  | C14663 |  |  |  | 50V | X7R
U30 | 74HCT595 | logic | SOIC-16 | TRUE | 1 | Opto-isolated USB interface for the Solartron 7075 50-way BCD port | A | 74HCT595 | 74HCT595D,118 | Nexperia | C282339
U31 | 74HCT595 | logic | SOIC-16 | TRUE | 1 | Opto-isolated USB interface for the Solartron 7075 50-way BCD port | A | 74HCT595 | 74HCT595D,118 | Nexperia | C282339
C55 | C-100nF-0603 | capacitor | C-0603 | TRUE | 1 | Opto-isolated USB interface for the Solartron 7075 50-way BCD port | A | 100nF | CC0603KRX7R9BB104 |  | C14663 |  |  |  | 50V | X7R
C56 | C-100nF-0603 | capacitor | C-0603 | TRUE | 1 | Opto-isolated USB interface for the Solartron 7075 50-way BCD port | A | 100nF | CC0603KRX7R9BB104 |  | C14663 |  |  |  | 50V | X7R
J1 | DSUB-50-PLUG-VERT | boardconnector | DSUB-50-PINS-VERT | TRUE | 1 | Opto-isolated USB interface for the Solartron 7075 50-way BCD port | A | DD-50 plug | DD50P364TXLF | Amphenol FCI | C5402574 | bottom side, vertical, mates with the meter |  |  |  |  |  |  | 2x 4-40 UNC jackscrew through board and flange

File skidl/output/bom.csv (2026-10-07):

Qty | Refs | Value | Footprint | MPN | Manufacturer | LCSC | Note
1 | C1 | 4.7n | C_0603_1608Metric | 0603B472K500NT | FH | C53987
3 | C2 C4 C25 | 10u | C_0603_1608Metric | CL10A106KP8NNNC | Samsung | C19702
2 | C3 C24 | 1u | C_0603_1608Metric | CL10A105KB8NNNC | Samsung | C15849
12 | C5 C6 C7 C8 C9 C10 C11 C12 C13 C17 C18 C19 | 100n | C_0402_1005Metric | CL05B104KO5NNNC | Samsung | C1525
3 | C14 C15 C16 | 4.7u | C_0402_1005Metric | CL05A475MP5NRNC | Samsung | C23733
2 | C20 C21 | 15p | C_0402_1005Metric | 0402CG150J500NT | FH | C1548
1 | C22 | 4.7u | C_0603_1608Metric | CL10A475KO8NNNC | Samsung | C19666
1 | C23 | 2.2u | C_0603_1608Metric | CL10A225KO8NNNC | Samsung | C23630
12 | C26 C27 C28 C29 C30 C31 C32 C33 C34 C35 C36 C37 | 100n | C_0603_1608Metric | CC0603KRX7R9BB104 | YAGEO | C14663
3 | D1 D2 D3 | green | LED_0603_1608Metric | LTST-C190KGKT | Lite-On | C125094
1 | D4 | red | LED_0603_1608Metric | KT-0603R | Hubei KENTO | C2286
1 | F1 | 500mA | Fuse_1206_3216Metric | SMD1206P050TF | RUILON | C20799
1 | J1 | DD-50 plug | DSUB-50_Pins_Vertical_P2.77x2.84mm_MountingHoles | D50P24A4PA00LF | Amphenol ICC | C17502305 | THT; LCSC lists it but often without stock - any DD-50 male straight PCB plug with 3.1 mm plain flange holes and the 2.77 x 2.84 mm grid fits
1 | J2 | USB_B | USB_B_TE_5787834_Vertical | 5787834-1 | TE Connectivity | C592900
1 | J3 | SWD | PinHeader_1x03_P2.54mm_Vertical | PZ254V-11-03P | XFCN | C2937625
1 | L1 | 3.3uH | L_Murata_DFE201610P | AOTA-B201610S3R3-101-T | Abracon | C42411119
1 | PS1 | B0509S-1WR3 | Converter_DCDC_Murata_MEE1SxxxxSC_THT | B0509S-1WR3 | EVISUN | C7500906 | Mornsun-style SIP-4 pinout (1 -Vin, 2 +Vin, 3 0V, 4 +Vo)
1 | Q1 | 2N7002 | SOT-23 | 2N7002 | CJ | C8545
1 | R1 | 1M | R_0603_1608Metric | 0603WAF1004T5E | UNI-ROYAL | C22935
3 | R2 R11 R13 | 1k | R_0603_1608Metric | 0603WAF1001T5E | UNI-ROYAL | C21190
1 | R3 | 33 | R_0402_1005Metric | 0402WGF330JTCE | UNI-ROYAL | C25105
3 | R4 R8 R9 | 1k | R_0402_1005Metric | 0402WGF1001TCE | UNI-ROYAL | C11702
2 | R5 R6 | 27 | R_0402_1005Metric | 0402WGF270JTCE | UNI-ROYAL | C25100
1 | R7 | 10k | R_0402_1005Metric | 0402WGF1002TCE | UNI-ROYAL | C25744
1 | R10 | 2.2k | R_0603_1608Metric | 0603WAF2201T5E | UNI-ROYAL | C4190
1 | R12 | 100k | R_0603_1608Metric | 0603WAF1003T5E | UNI-ROYAL | C25803
4 | R14 R15 R16 R17 | 390 | R_0603_1608Metric | 0603WAF3900T5E | UNI-ROYAL | C23151
1 | R18 | 820 | R_0603_1608Metric | 0603WAF8200T5E | UNI-ROYAL | C23253
9 | RN1 RN2 RN3 RN4 RN5 RN6 RN7 RN8 RN9 | 10k | R_Array_Convex_4x0603 | 4D03WGJ0103T5E | UNI-ROYAL | C29718
1 | SW1 | BOOTSEL | SW_Push_1P1T_XKB_TS-1187A | TS-1187A-B-A-B | XKB Connection | C318884
1 | SW2 | RESET | SW_Push_1P1T_XKB_TS-1187A | TS-1187A-B-A-B | XKB Connection | C318884
1 | U1 | RP2354A | QFN-60-1EP_7x7mm_P0.4mm_EP3.4x3.4mm_ThermalVias | RP2354A | Raspberry Pi | C41378174
1 | U2 | AP2112K-3.3 | SOT-23-5 | AP2112K-3.3TRG1 | Diodes Incorporated | C51118
1 | U3 | USBLC6-2SC6 | SOT-23-6 | USBLC6-2SC6 | STMicroelectronics | C7519
1 | U4 | 78L05 | SOT-89-3 | 78L05 (SOT-89) | UMW | C347258
5 | U5 U6 U7 U8 U9 | TLP2361 | Toshiba_SOIC-5-6_4.4x3.6mm_P1.27mm | TLP2361(TPL,E | Toshiba | C107626 | KiCad TLP2310 symbol used (identical SO6/5-lead pinout)
5 | U10 U11 U12 U13 U14 | 74HCT165 | SOIC-16_3.9x9.9mm_P1.27mm | 74HCT165D,653 | Nexperia | C456131
2 | U15 U16 | 74HC595 | SOIC-16_3.9x9.9mm_P1.27mm | 74HC595D,118 | Nexperia | C5947
1 | Y1 | 12MHz | Crystal_SMD_3225-4Pin_3.2x2.5mm | ABM8-272-T3 | Abracon | C20625731
2 | - | Jackscrew 4-40 UNC, >= 10 mm thread | - | any D-sub jackscrew / thumbscrew (e.g. Norcomp 4-40 thumbscrew) | - | - | fits through J1's 3.2 mm flange holes into the meter's socket screw-locks; check the thread on your 70754 (4-40 UNC is the D-sub standard)

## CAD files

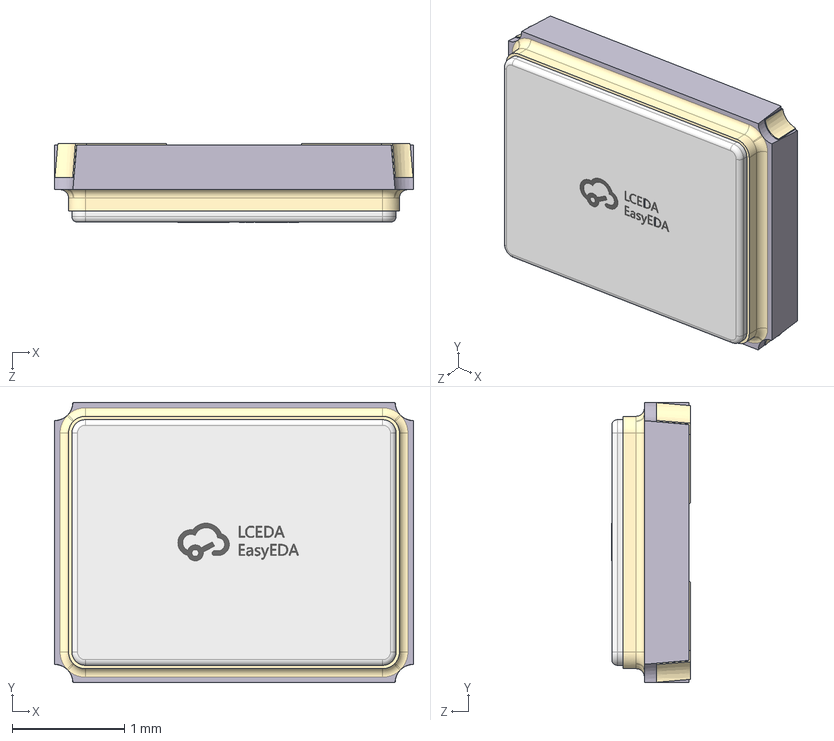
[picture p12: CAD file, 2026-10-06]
atopile/parts/Abracon_LLC_ABM8_272_T3/OSC-SMD_L3.2-W1.5-H0.8.STEP
3.20 x 2.50 x 0.701 mm

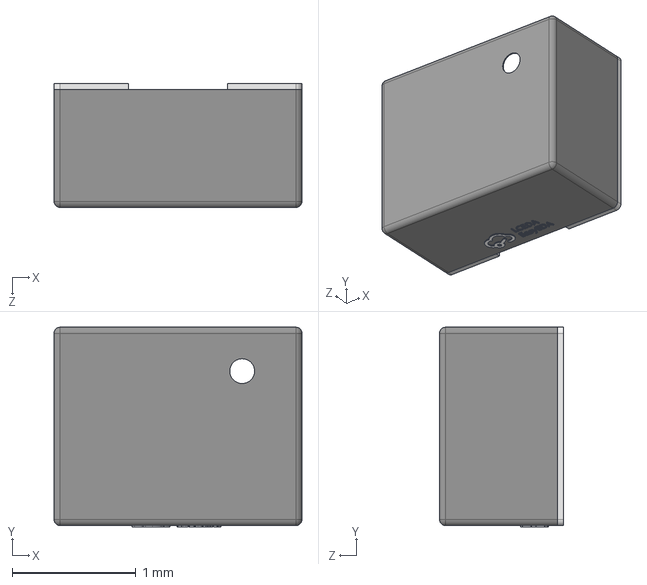
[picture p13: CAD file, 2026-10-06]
atopile/parts/Abracon_LLC_AOTA_B201610S3R3_101_T/IND-SMD_L2.0-W1.6_AOTA-B201610S3R3-101-T.STEP
2.00 x 1.61 x 1.00 mm

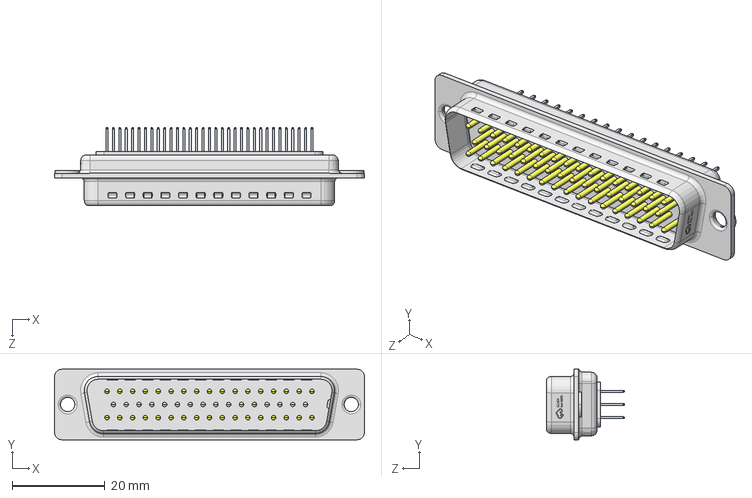
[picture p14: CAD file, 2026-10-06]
atopile/parts/Amphenol_ICC_DD50P364TXLF/CONN-TH_50P-P2.76_DD50P364TXLF.STEP
66.8 x 15.2 x 16.8 mm

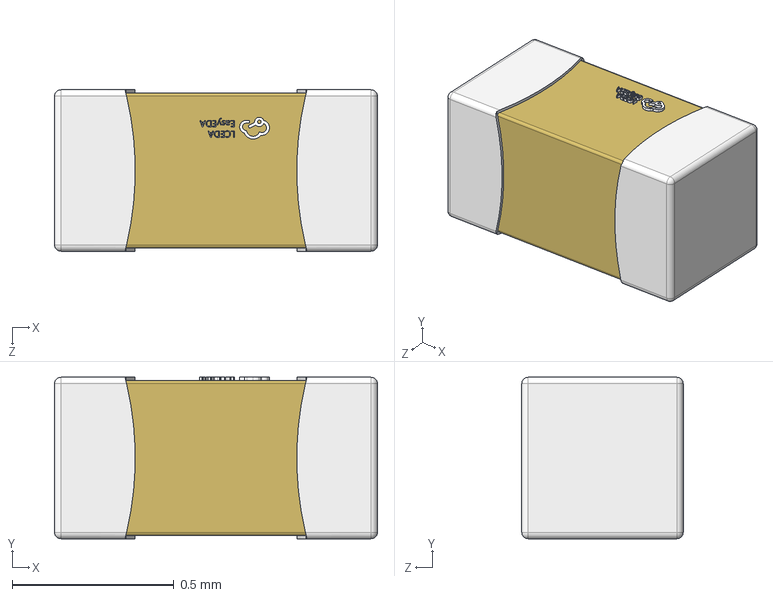
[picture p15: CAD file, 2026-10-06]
atopile/parts/FH_0402CG150J500NT/C0402_L1.0-W0.5-H0.5.step
1.00 x 0.5 x 0.5 mm

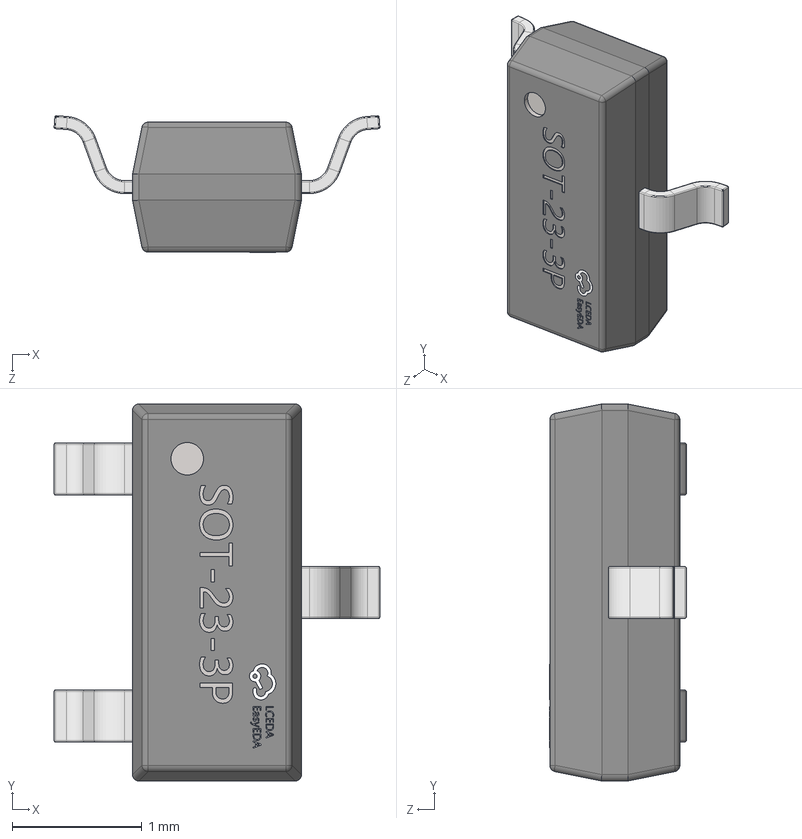
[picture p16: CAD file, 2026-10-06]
atopile/parts/Jiangsu_Changjing_Electronics_Technology_Co___Ltd_2N7002/SOT-23-3P_L2.9-W1.3-H1.0-LS2.4-P0.95.step
2.51 x 2.90 x 1.05 mm

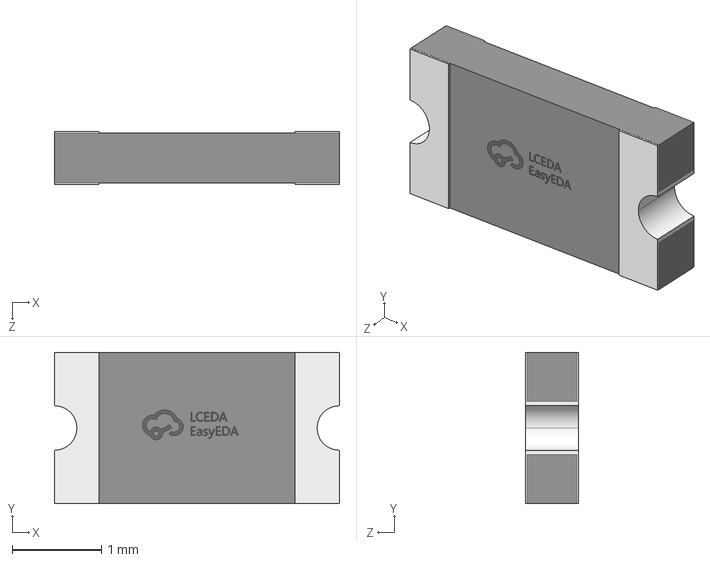
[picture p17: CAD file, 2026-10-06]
atopile/parts/LUTE_1206L050_36NR/F1206_L3.2-W1.7-H0.6.step
3.20 x 1.70 x 0.6 mm

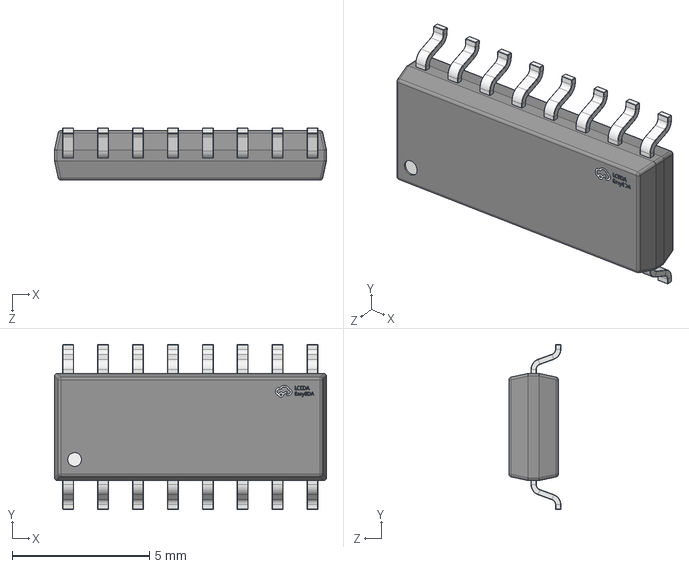
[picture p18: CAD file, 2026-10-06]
atopile/parts/Nexperia_74HCT595D_118/SOIC-16_L9.9-W3.9-H1.8-LS6.0-P1.27.step
9.90 x 6.01 x 1.90 mm

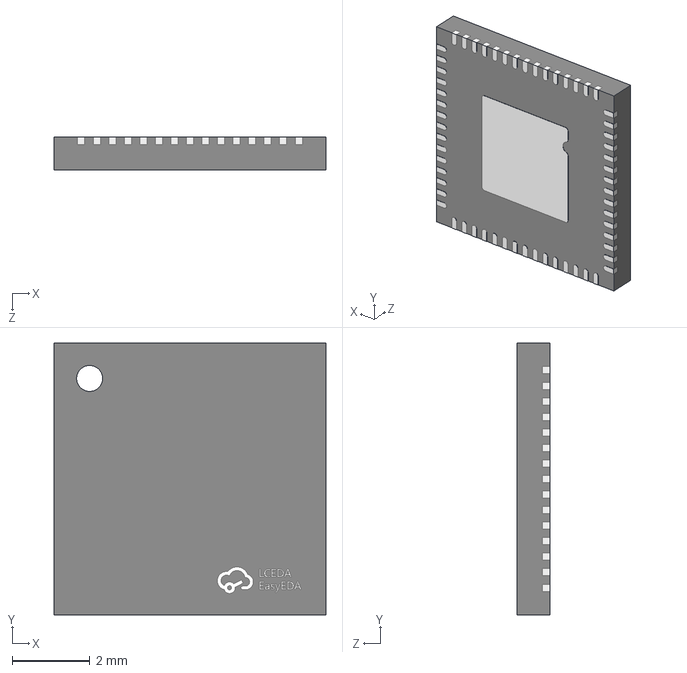
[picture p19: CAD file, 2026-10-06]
atopile/parts/Raspberry_Pi_RP2354A/QFN-60_L7.0-W7.0-P0.40-TL-EP3.4.STEP
7.00 x 7.00 x 0.861 mm

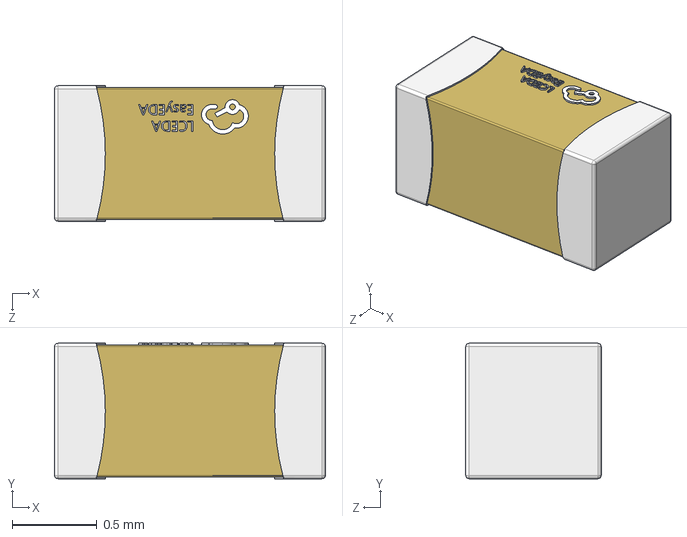
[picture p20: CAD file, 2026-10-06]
atopile/parts/Samsung_Electro_Mechanics_CL10A106KP8NNNC/C0603_L1.6-W0.8-H0.8.step
1.60 x 0.8 x 0.8 mm

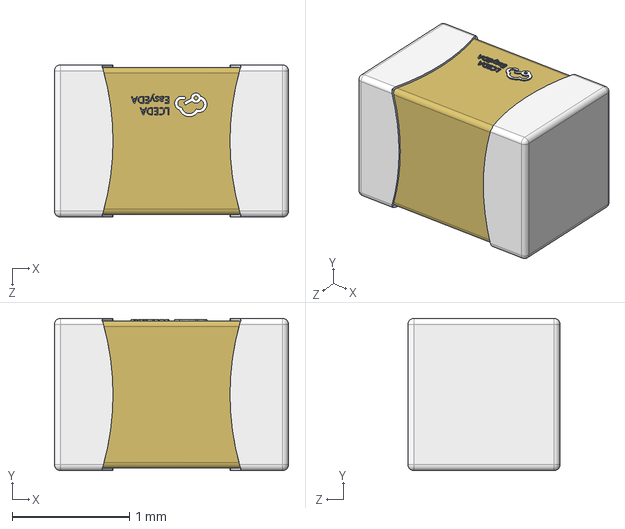
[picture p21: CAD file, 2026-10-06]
atopile/parts/Samsung_Electro_Mechanics_CL21A106KAYNNNE/C0805_L2.0-W1.3-H1.3.step
2.00 x 1.30 x 1.30 mm

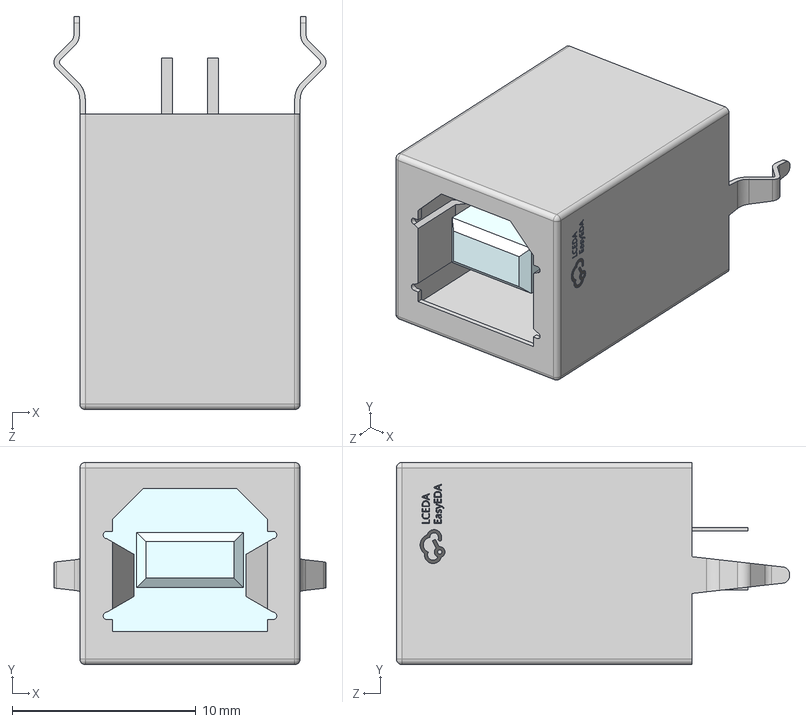
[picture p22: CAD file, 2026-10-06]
atopile/parts/SHOU_HAN_BF_180/USB-B-TH_921-111A1010Y10201.step
14.8 x 11.0 x 21.4 mm

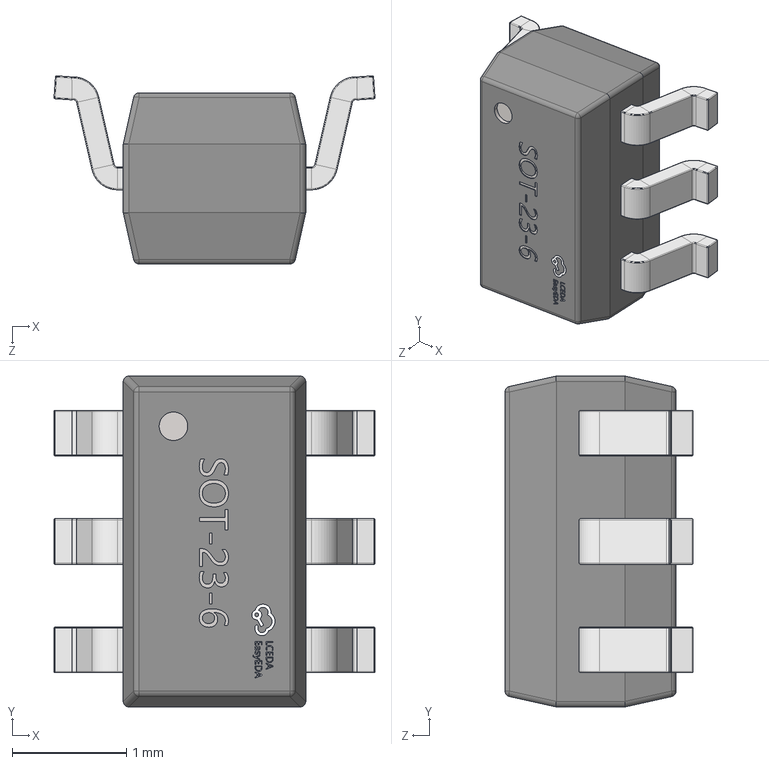
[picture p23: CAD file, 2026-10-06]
atopile/parts/STMicroelectronics_USBLC6_2SC6/SOT-23-6_L2.9-W1.6-H1.5-LS2.8-P0.95.step
2.81 x 2.90 x 1.65 mm

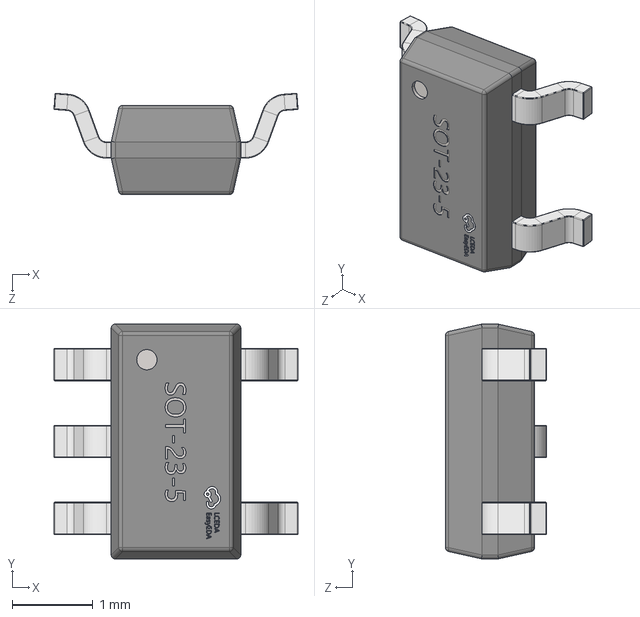
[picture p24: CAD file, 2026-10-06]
atopile/parts/Texas_Instruments_SN74AHCT1G125DBVR/SOT-23-5_L2.9-W1.6-H1.1-LS2.8-P0.95.step
3.01 x 2.90 x 1.25 mm

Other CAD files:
atopile/parts/TOSHIBA_TLP2361_TPL_E/1.STEP
atopile/parts/UNI_ROYAL_0402WGF1001TCE/R0402_L1.0-W0.5-H0.4.step
atopile/parts/UNI_ROYAL_0402WGF1002TCE/R0402_L1.0-W0.5-H0.4.step
atopile/parts/UNI_ROYAL_0402WGF1003TCE/R0402_L1.0-W0.5-H0.4.step
atopile/parts/UNI_ROYAL_0402WGF1501TCE/R0402_L1.0-W0.5-H0.4.step
atopile/parts/UNI_ROYAL_0402WGF2002TCE/R0402_L1.0-W0.5-H0.4.step
atopile/parts/UNI_ROYAL_0402WGF270JTCE/R0402_L1.0-W0.5-H0.4.step
atopile/parts/UNI_ROYAL_0402WGF3300TCE/R0402_L1.0-W0.5-H0.4.step
atopile/parts/UNI_ROYAL_0402WGF3301TCE/R0402_L1.0-W0.5-H0.4.step
atopile/parts/UNI_ROYAL_0402WGF330JTCE/R0402_L1.0-W0.5-H0.4.step
atopile/parts/UNI_ROYAL_0402WGF6800TCE/R0402_L1.0-W0.5-H0.4.step
atopile/parts/YLPTEC_IB0505LS_1WR3/PWRM-TH_BXXXXLS-1WR3.step

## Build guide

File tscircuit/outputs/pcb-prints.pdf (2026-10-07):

TOP (component side) | BOTTOM (D-sub side, viewed from below)

## Board views

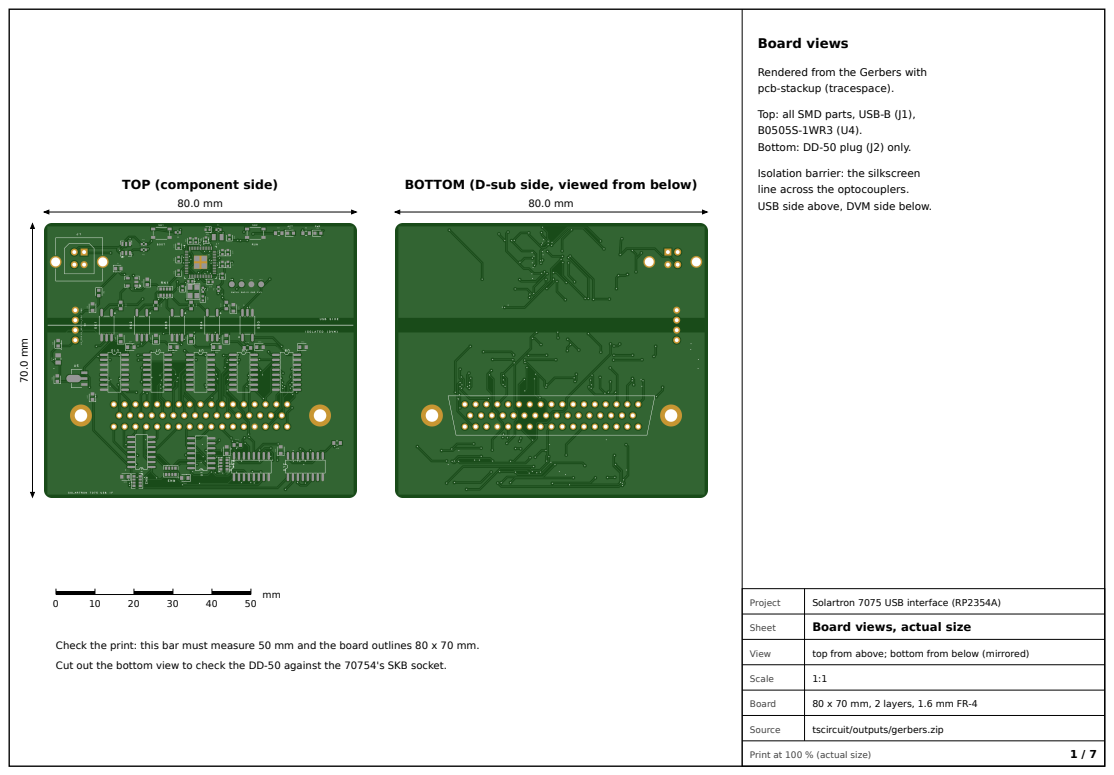
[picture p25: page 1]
Project; Solartron 7075 USB interface (RP2354A); Sheet; Board views, actual size; View; top from above; bottom from below (mirrored); Scale; Board; 80 x 70 mm, 2 layers, 1.6 mm FR-4; Source; tscircuit/outputs/gerbers.zip; Print at 100 % (actual size)

Rendered from the Gerbers with
pcb-stackup (tracespace).

Top: all SMD parts, USB-B (J1),
Bottom: DD-50 plug (J2) only.

Isolation barrier: the silkscreen
line across the optocouplers.
USB side above, DVM side below.

Check the print: this bar must measure 50 mm and the board outlines 80 x 70 mm.
Cut out the bottom view to check the DD-50 against the 70754's SKB socket.

## Top copper

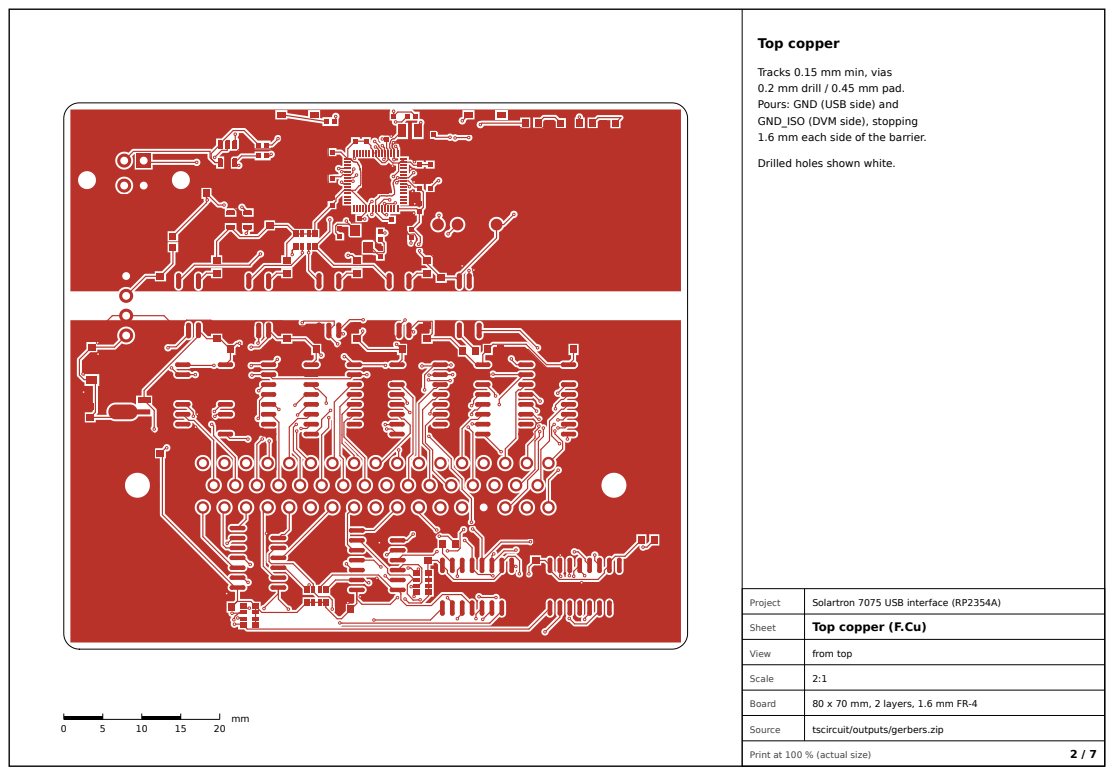
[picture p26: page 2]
Project; Solartron 7075 USB interface (RP2354A); Sheet; Top copper (F.Cu); View; from top; Scale; Board; 80 x 70 mm, 2 layers, 1.6 mm FR-4

Tracks 0.15 mm min, vias
0.2 mm drill / 0.45 mm pad.
Pours: GND (USB side) and
GND_ISO (DVM side), stopping
1.6 mm each side of the barrier.

Drilled holes shown white.

## Bottom copper

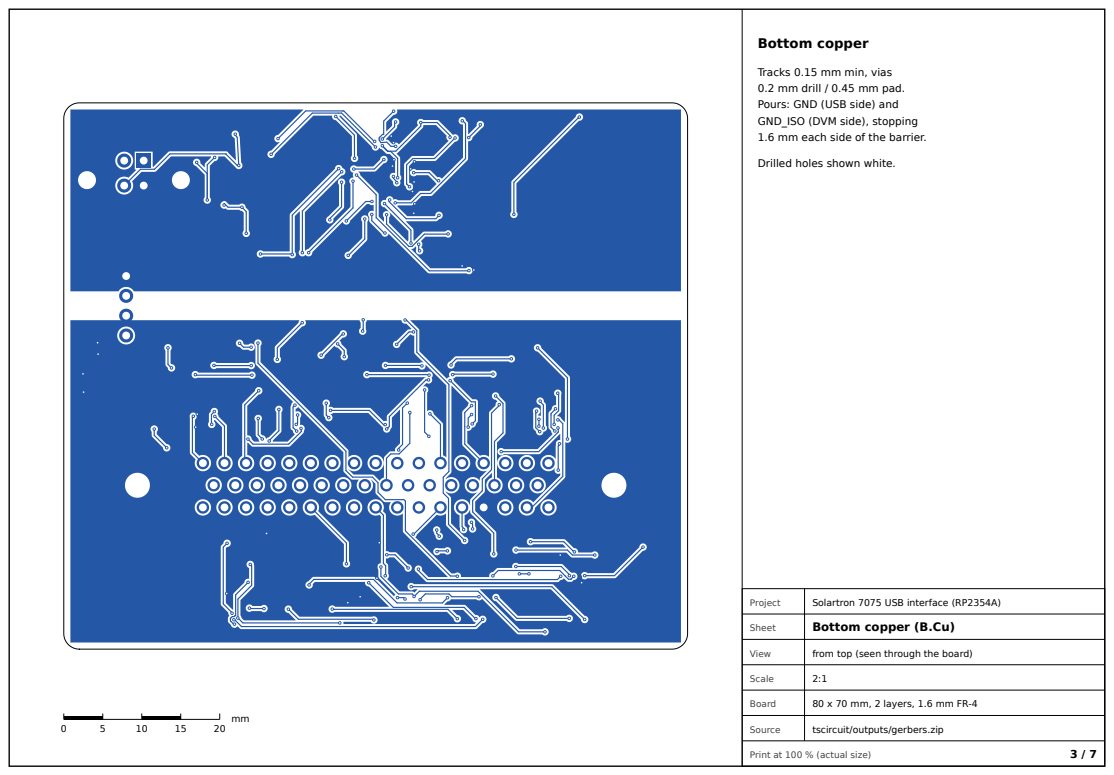
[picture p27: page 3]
Project; Solartron 7075 USB interface (RP2354A); Sheet; Bottom copper (B.Cu); View; from top (seen through the board); Scale; Board; 80 x 70 mm, 2 layers, 1.6 mm FR-4

Tracks 0.15 mm min, vias
0.2 mm drill / 0.45 mm pad.
Pours: GND (USB side) and
GND_ISO (DVM side), stopping
1.6 mm each side of the barrier.

Drilled holes shown white.

## Top assembly

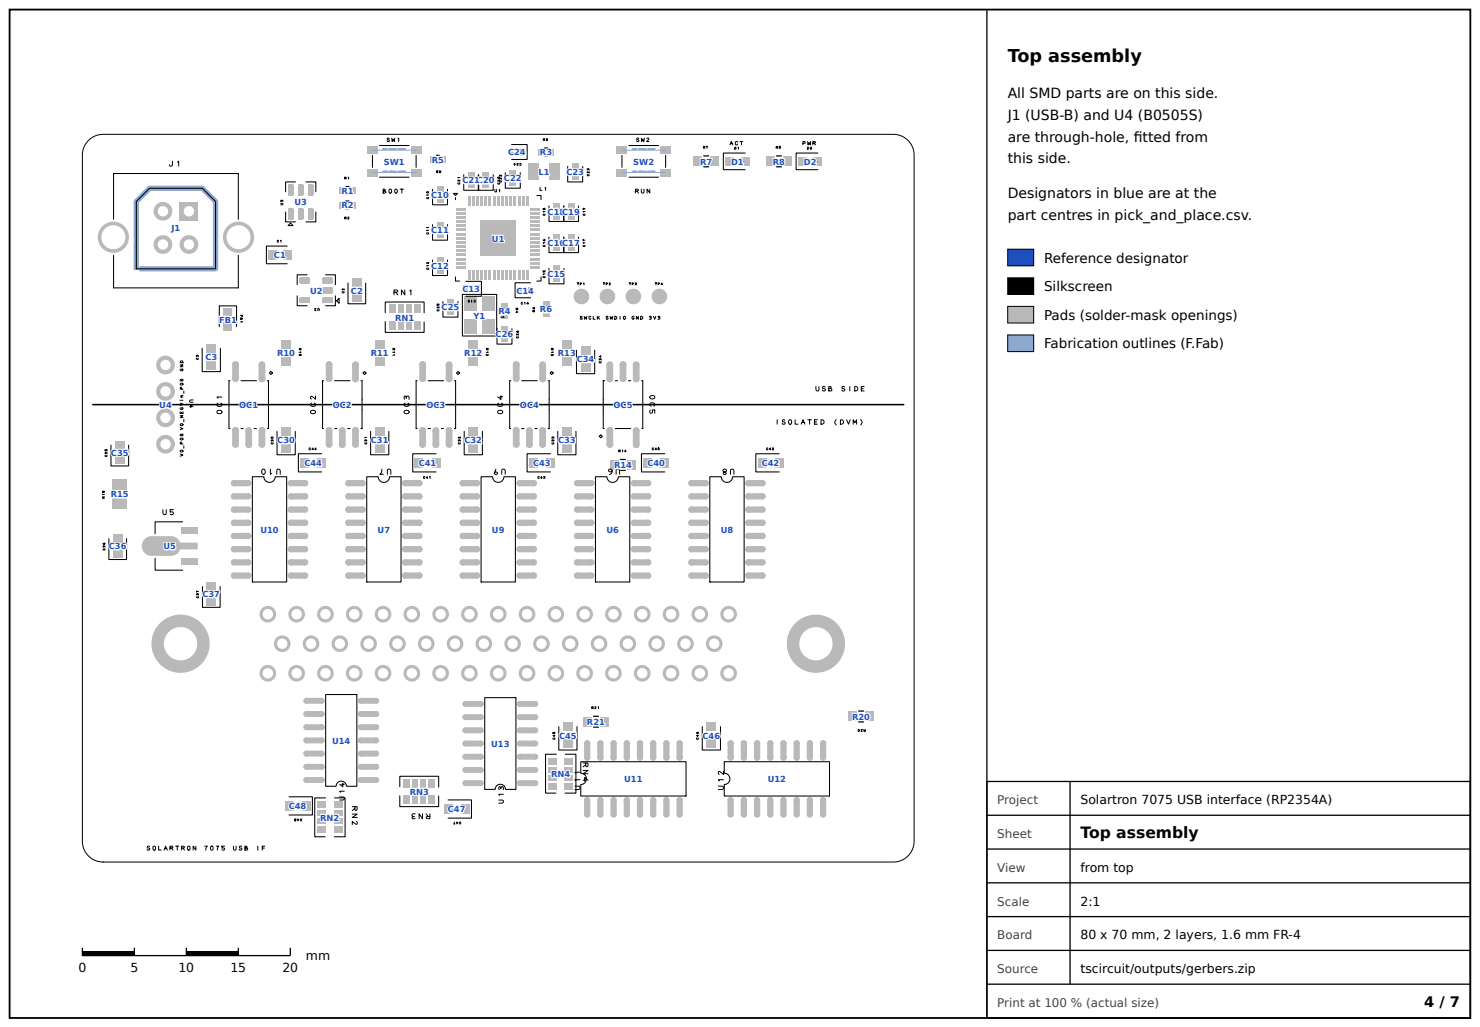
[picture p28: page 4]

All SMD parts are on this side.
J1 (USB-B) and U4 (B0505S)
are through-hole, fitted from
this side.

Designators in blue are at the
part centres in pick_and_place.csv.

Reference designator
Silkscreen
Pads (solder-mask openings)
Fabrication outlines (F.Fab)

## Bottom assembly

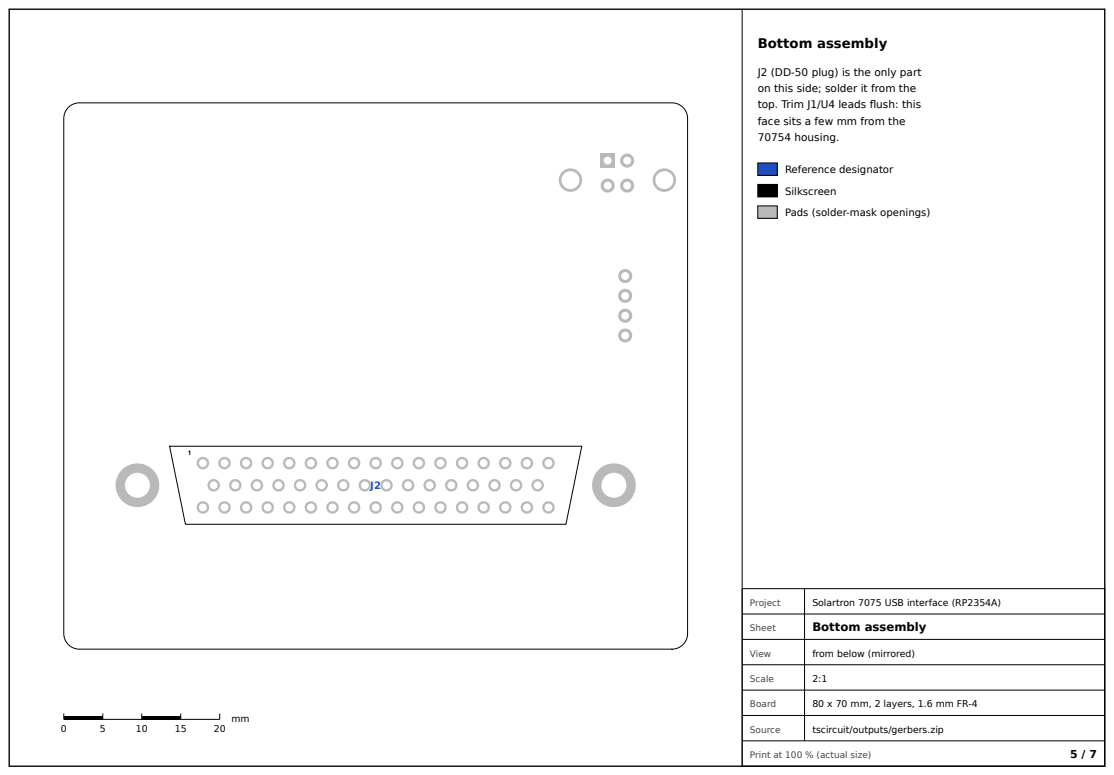
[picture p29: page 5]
Project; Solartron 7075 USB interface (RP2354A); Sheet; Bottom assembly; View; from below (mirrored); Scale; Board; 80 x 70 mm, 2 layers, 1.6 mm FR-4

J2 (DD-50 plug) is the only part
on this side; solder it from the
top. Trim J1/U4 leads flush: this
face sits a few mm from the
70754 housing.

Reference designator
Silkscreen
Pads (solder-mask openings)

## Top stencil

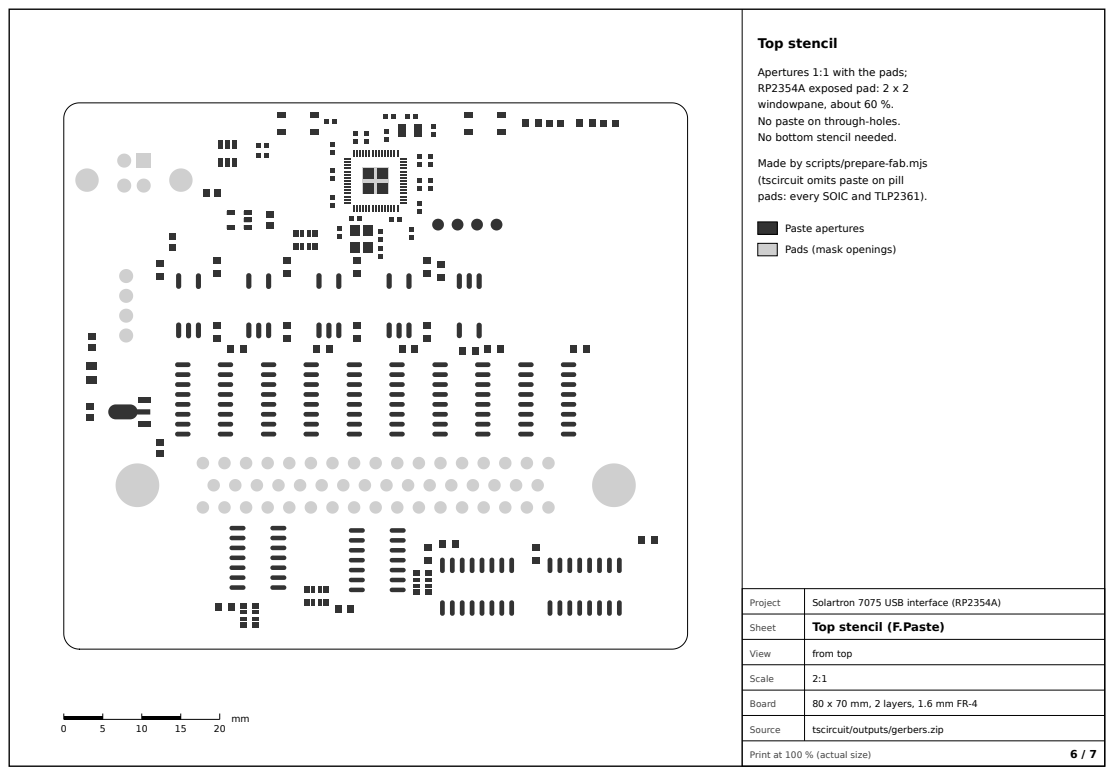
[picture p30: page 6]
Project; Solartron 7075 USB interface (RP2354A); Sheet; Top stencil (F.Paste); View; from top; Scale; Board; 80 x 70 mm, 2 layers, 1.6 mm FR-4

Apertures 1:1 with the pads;
RP2354A exposed pad: 2 x 2
windowpane, about 60 %.
No paste on through-holes.
No bottom stencil needed.

Made by scripts/prepare-fab.mjs
(tscircuit omits paste on pill
pads: every SOIC and TLP2361).

Paste apertures
Pads (mask openings)

## Drill drawing

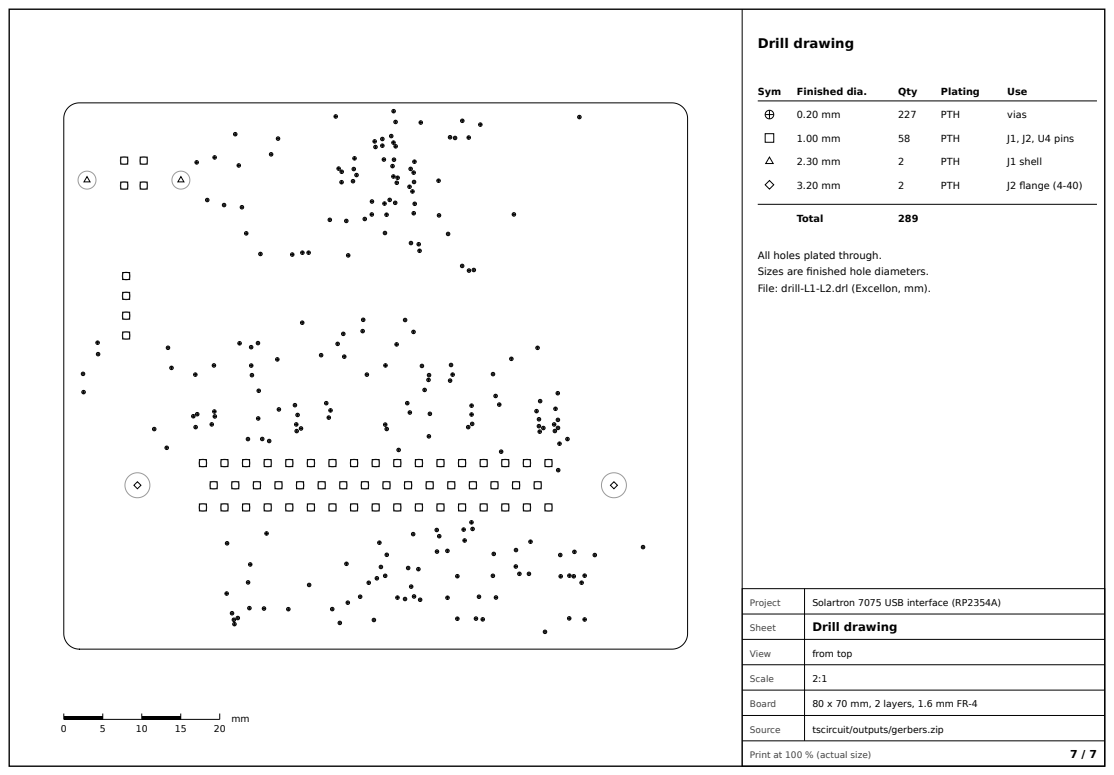
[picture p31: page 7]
Sym; Finished dia.; Qty; Plating; Use; PTH; vias; J1, J2, U4 pins; J1 shell; J2 flange (4-40); Total; Project; Solartron 7075 USB interface (RP2354A); Sheet; Drill drawing; View; from top; Scale; Board; 80 x 70 mm, 2 layers, 1.6 mm FR-4

All holes plated through.
Sizes are finished hole diameters.
File: drill-L1-L2.drl (Excellon, mm).

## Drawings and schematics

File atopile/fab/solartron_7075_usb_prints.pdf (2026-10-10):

1 | 2 | 3 | 4 | 5 | 6

AB

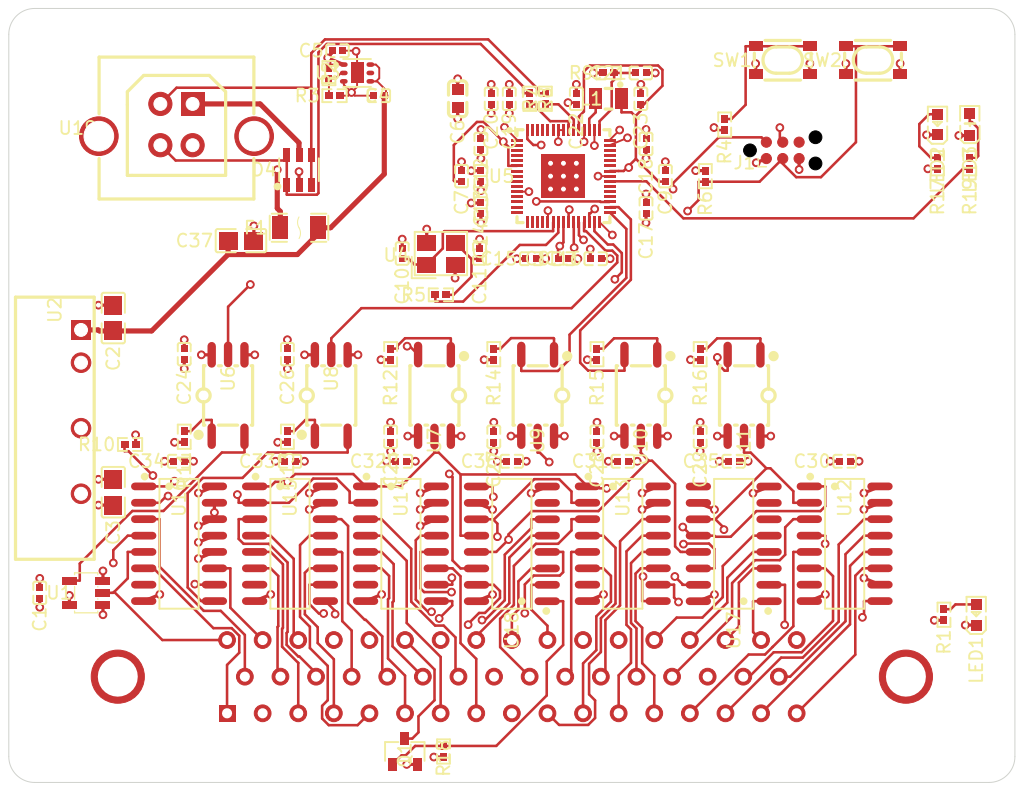
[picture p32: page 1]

Print at 100% / actual size for fit checks
Rev A
atopile design (../*.ato)
Sheet:
File: solartron_7075_usb.kicad_pcb
Title: Solartron 7075 USB interface
KiCad E.D.A. 10.0.6

AB

AB

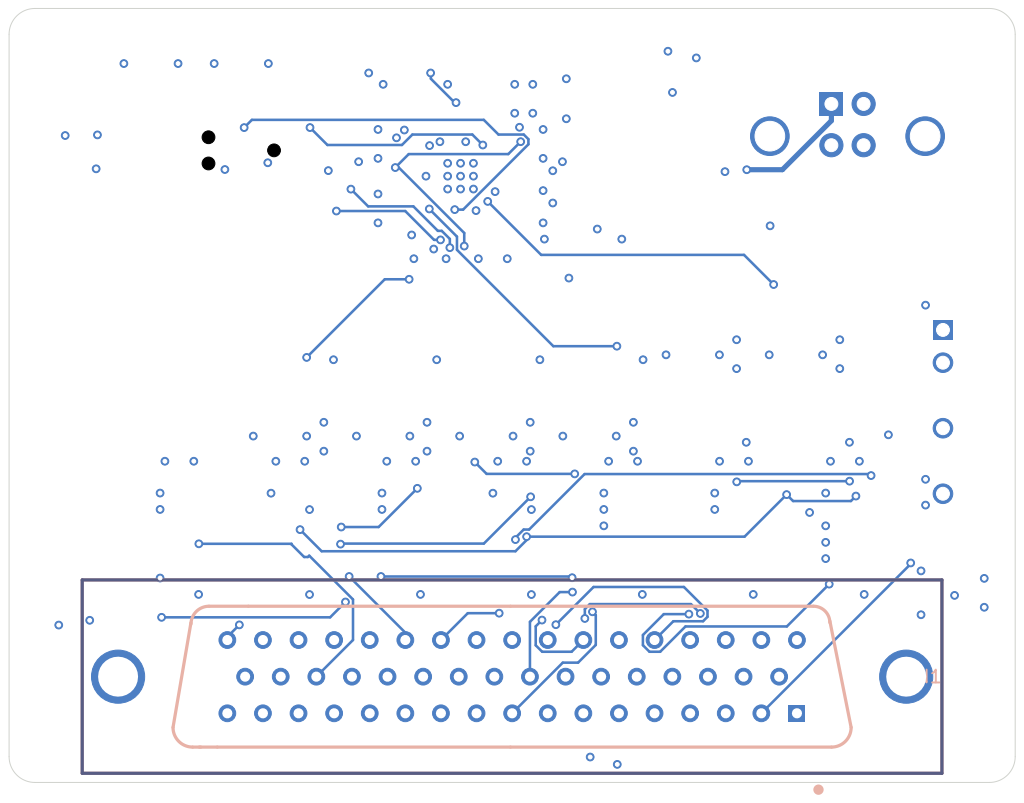
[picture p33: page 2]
D Date: 2026-10-09

Bottom, mirrored = as seen from the meter. Hold against SKB to check the DD-50 fit CN1

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

AB

AB

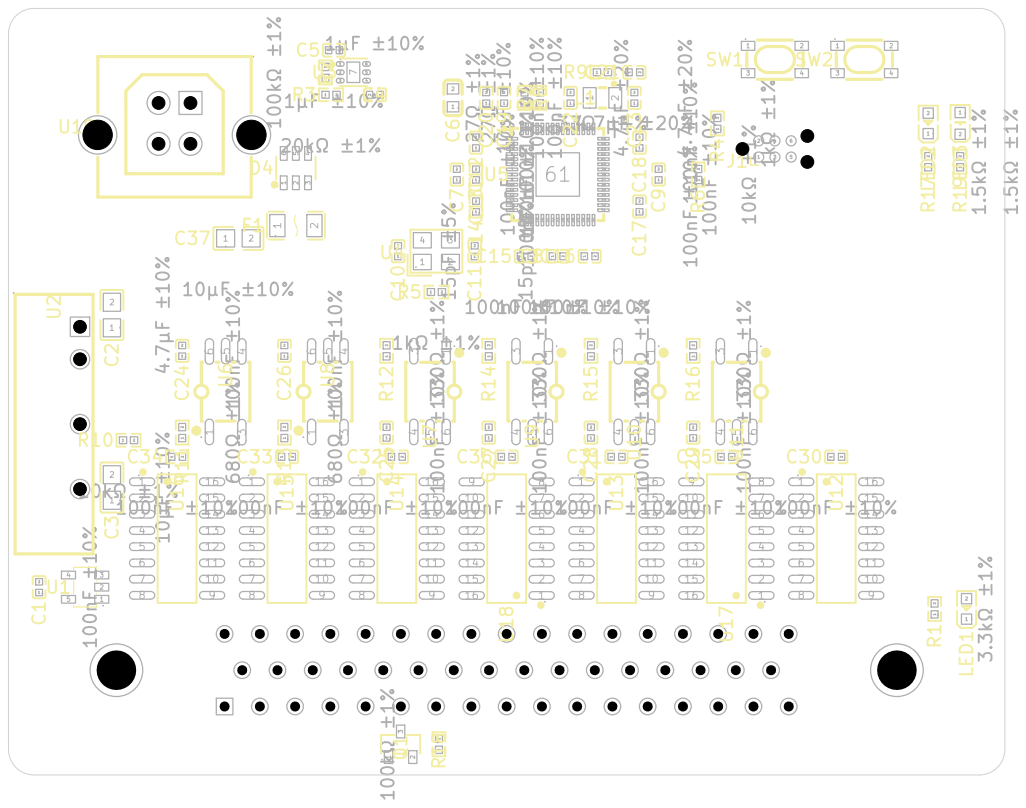
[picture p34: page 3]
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

AB

AB

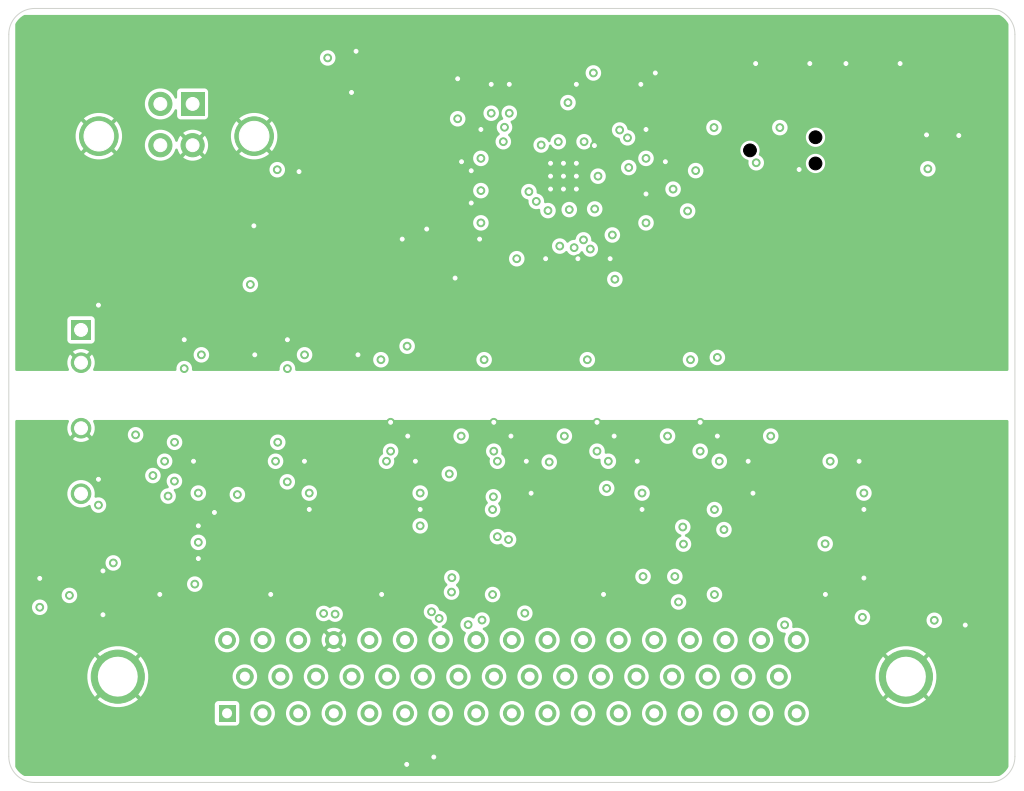
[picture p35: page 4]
D Date: 2026-10-09

In1.Cu: GND | GND_ISO planes (top view)
Print at 100% / actual size for fit checks
Rev A
atopile design (../*.ato)
Sheet:
File: solartron_7075_usb.kicad_pcb
Title: Solartron 7075 USB interface

AB

AB

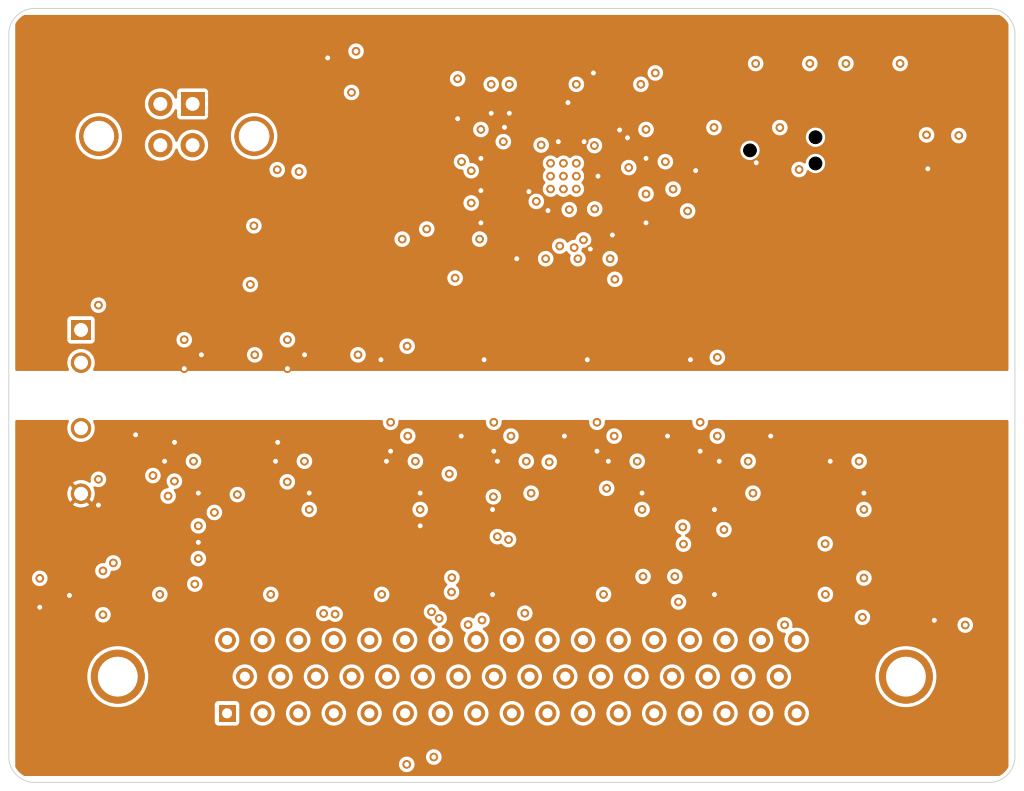
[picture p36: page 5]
D Date: 2026-10-09

In2.Cu: +3V3 | +5V_ISO planes (top view)
Print at 100% / actual size for fit checks
Rev A
atopile design (../*.ato)
Sheet:
File: solartron_7075_usb.kicad_pcb
Title: Solartron 7075 USB interface

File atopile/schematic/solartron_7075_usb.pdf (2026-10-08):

1 | 2 | 3 | 4 | 5 | 6 | 7 | 8

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
Size: A3 | Rev: A | F Date: 2026-10-07
KiCad E.D.A. 10.0.6 | Id: 1/5

## Title: Solartron 7075 USB interface - overview

### File: solartron_7075_usb.kicad_sch

### Sheet: /

## atopile design (../*.ato)

### Auto-generated from the atopile netlist by scripts/export_schematic.py

### The .ato files are the source of truth - do not edit this schematic

## 2. USB input and power

File: power_usb.kicad_sch

## 3. RP2354A

## File: mcu.kicad_sch 4. Isolation barrier

## File: isolation.kicad_sch 5. Solartron SKB interface

File: dvm.kicad_sch

USB-B -> 500 mA PTC + USBLC6 ESD -> +5V.
+5V -> TLV75901 (100k/20k feedback) -> +3V3.
+5V -> IB0505LS-1WR3 isolated DC-DC -> +5V_ISO / GND_ISO (DVM side).

RP2354A (2 MB in-package flash). Core regulator per RP2350 datasheet:
3.3 uH polarity-marked inductor, 4.7 uF CIN/COUT, 33R + 4.7 uF on VREG_AVDD.
GPIO16 MISO, GPIO17 LATCH, GPIO18 SCK, GPIO19 MOSI, GPIO20 OE_N, GPIO21 DRDY, GPIO25 status LED.

Six non-inverting TLP2361 channels. The LED cathode is driven by the source, the anode is fed through 330R (3.3 V side) or 680R (5 V side), ~4.5 mA.

Undriven inputs leave the outputs HIGH (OE_N_ISO high = 595 outputs Hi-Z).

SKB pins 1-36 -> 5x 74HCT165 (frame bit k = SKB pin k+1, then 1010 signature). 2x 74HCT595 -> SKB 38, 40-50; 2N7002 contact-closure SAMPLE on SKB 39. SKB 37 = DVM earth / logic 0 = GND_ISO. See README.md for the bit map.

## Solartron 7075 USB interface

RP2354A USB interface for the Solartron 7075 DVM + 70754 Parallel BCD Interface (SKB, 50-way Cannon). Everything to/from the meter is opto-isolated: only SCK, MOSI, LATCH, OE_N, MISO and DRDY cross the barrier. Nets are joined by name (global labels). GND (USB side) and GND_ISO (DVM side) are never joined.

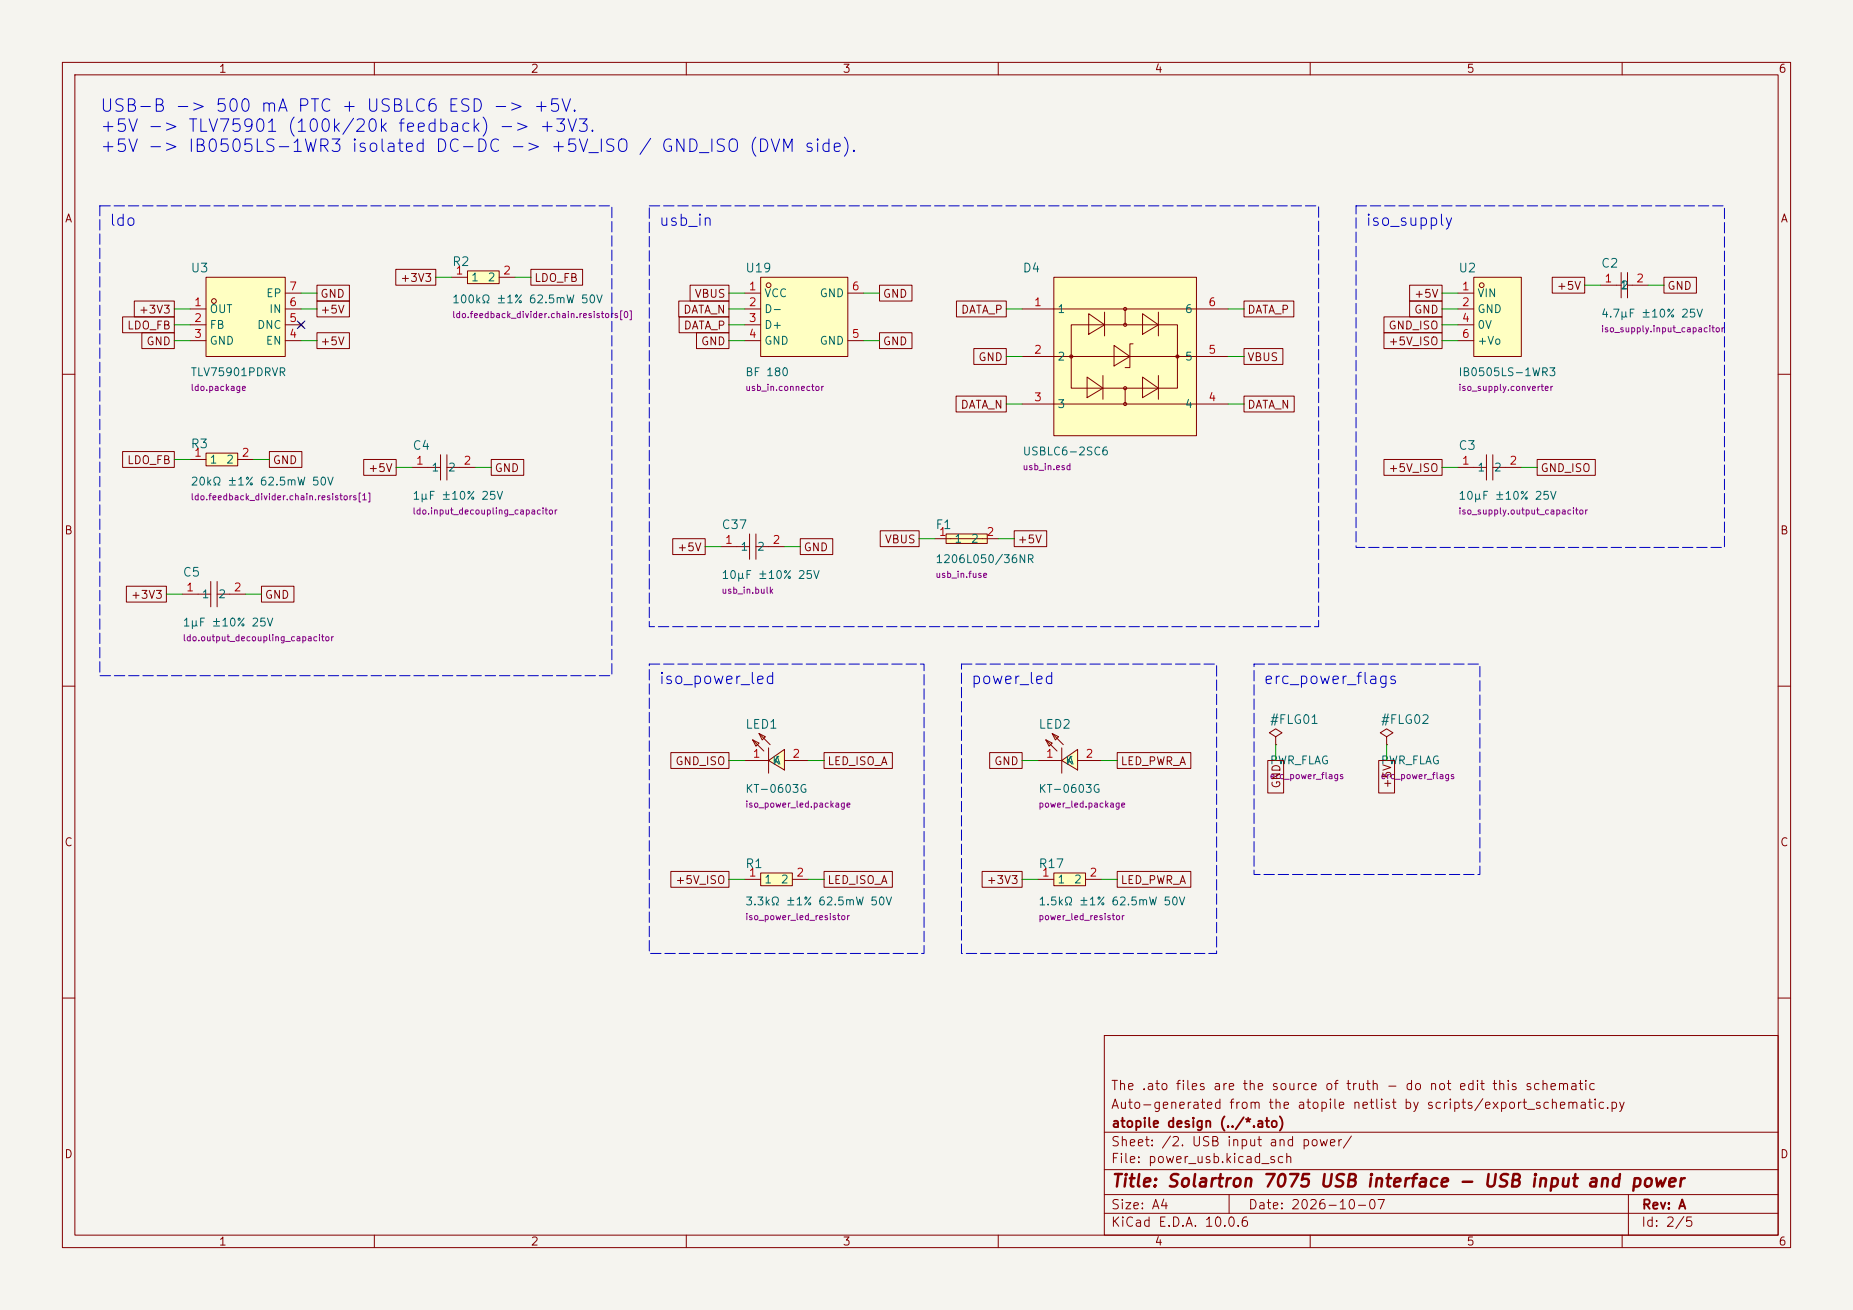
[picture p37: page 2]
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

ldo.feedback_divider.chain.resistors[1] OUT 1

The .ato files are the source of truth - do not edit this schematic
Auto-generated from the atopile netlist by scripts/export_schematic.py
atopile design (../*.ato)
Sheet: /2. USB input and power/
File: power_usb.kicad_sch
Title: Solartron 7075 USB interface - USB input and power

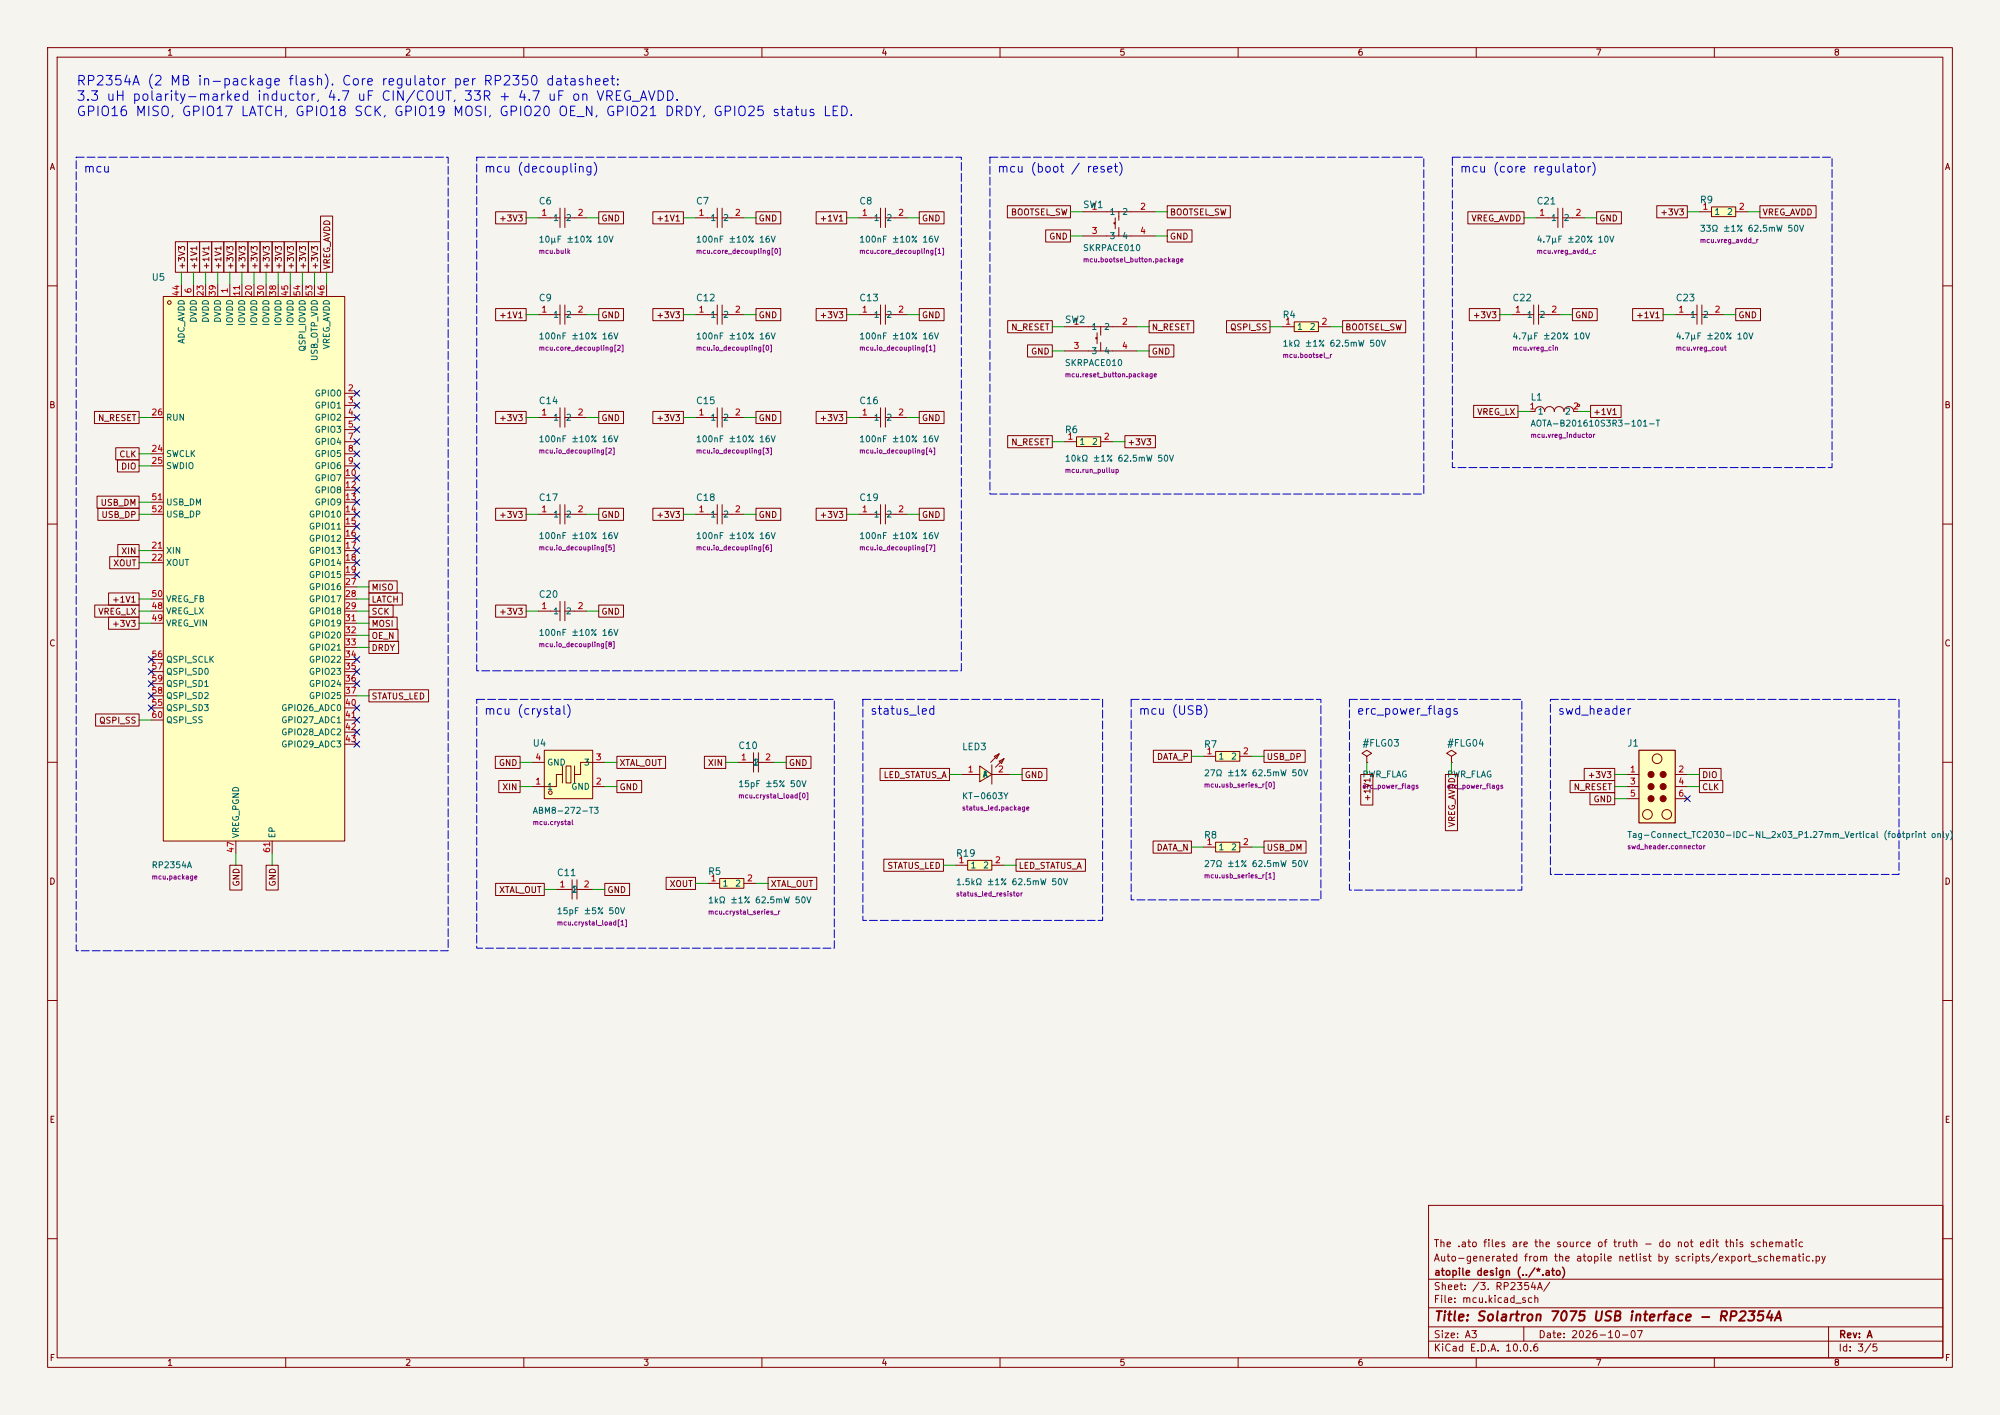
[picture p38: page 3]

RP2354A (2 MB in-package flash). Core regulator per RP2350 datasheet:
3.3 uH polarity-marked inductor, 4.7 uF CIN/COUT, 33R + 4.7 uF on VREG_AVDD.
GPIO16 MISO, GPIO17 LATCH, GPIO18 SCK, GPIO19 MOSI, GPIO20 OE_N, GPIO21 DRDY, GPIO25 status LED. mcu (decoupling)

Tag-Connect_TC2030-IDC-NL_2x03_P1.27mm_Vertical (footprint only)
swd_header.connector

The .ato files are the source of truth - do not edit this schematic
Auto-generated from the atopile netlist by scripts/export_schematic.py
atopile design (../*.ato)
Sheet: /3. RP2354A/
File: mcu.kicad_sch
Title: Solartron 7075 USB interface - RP2354A

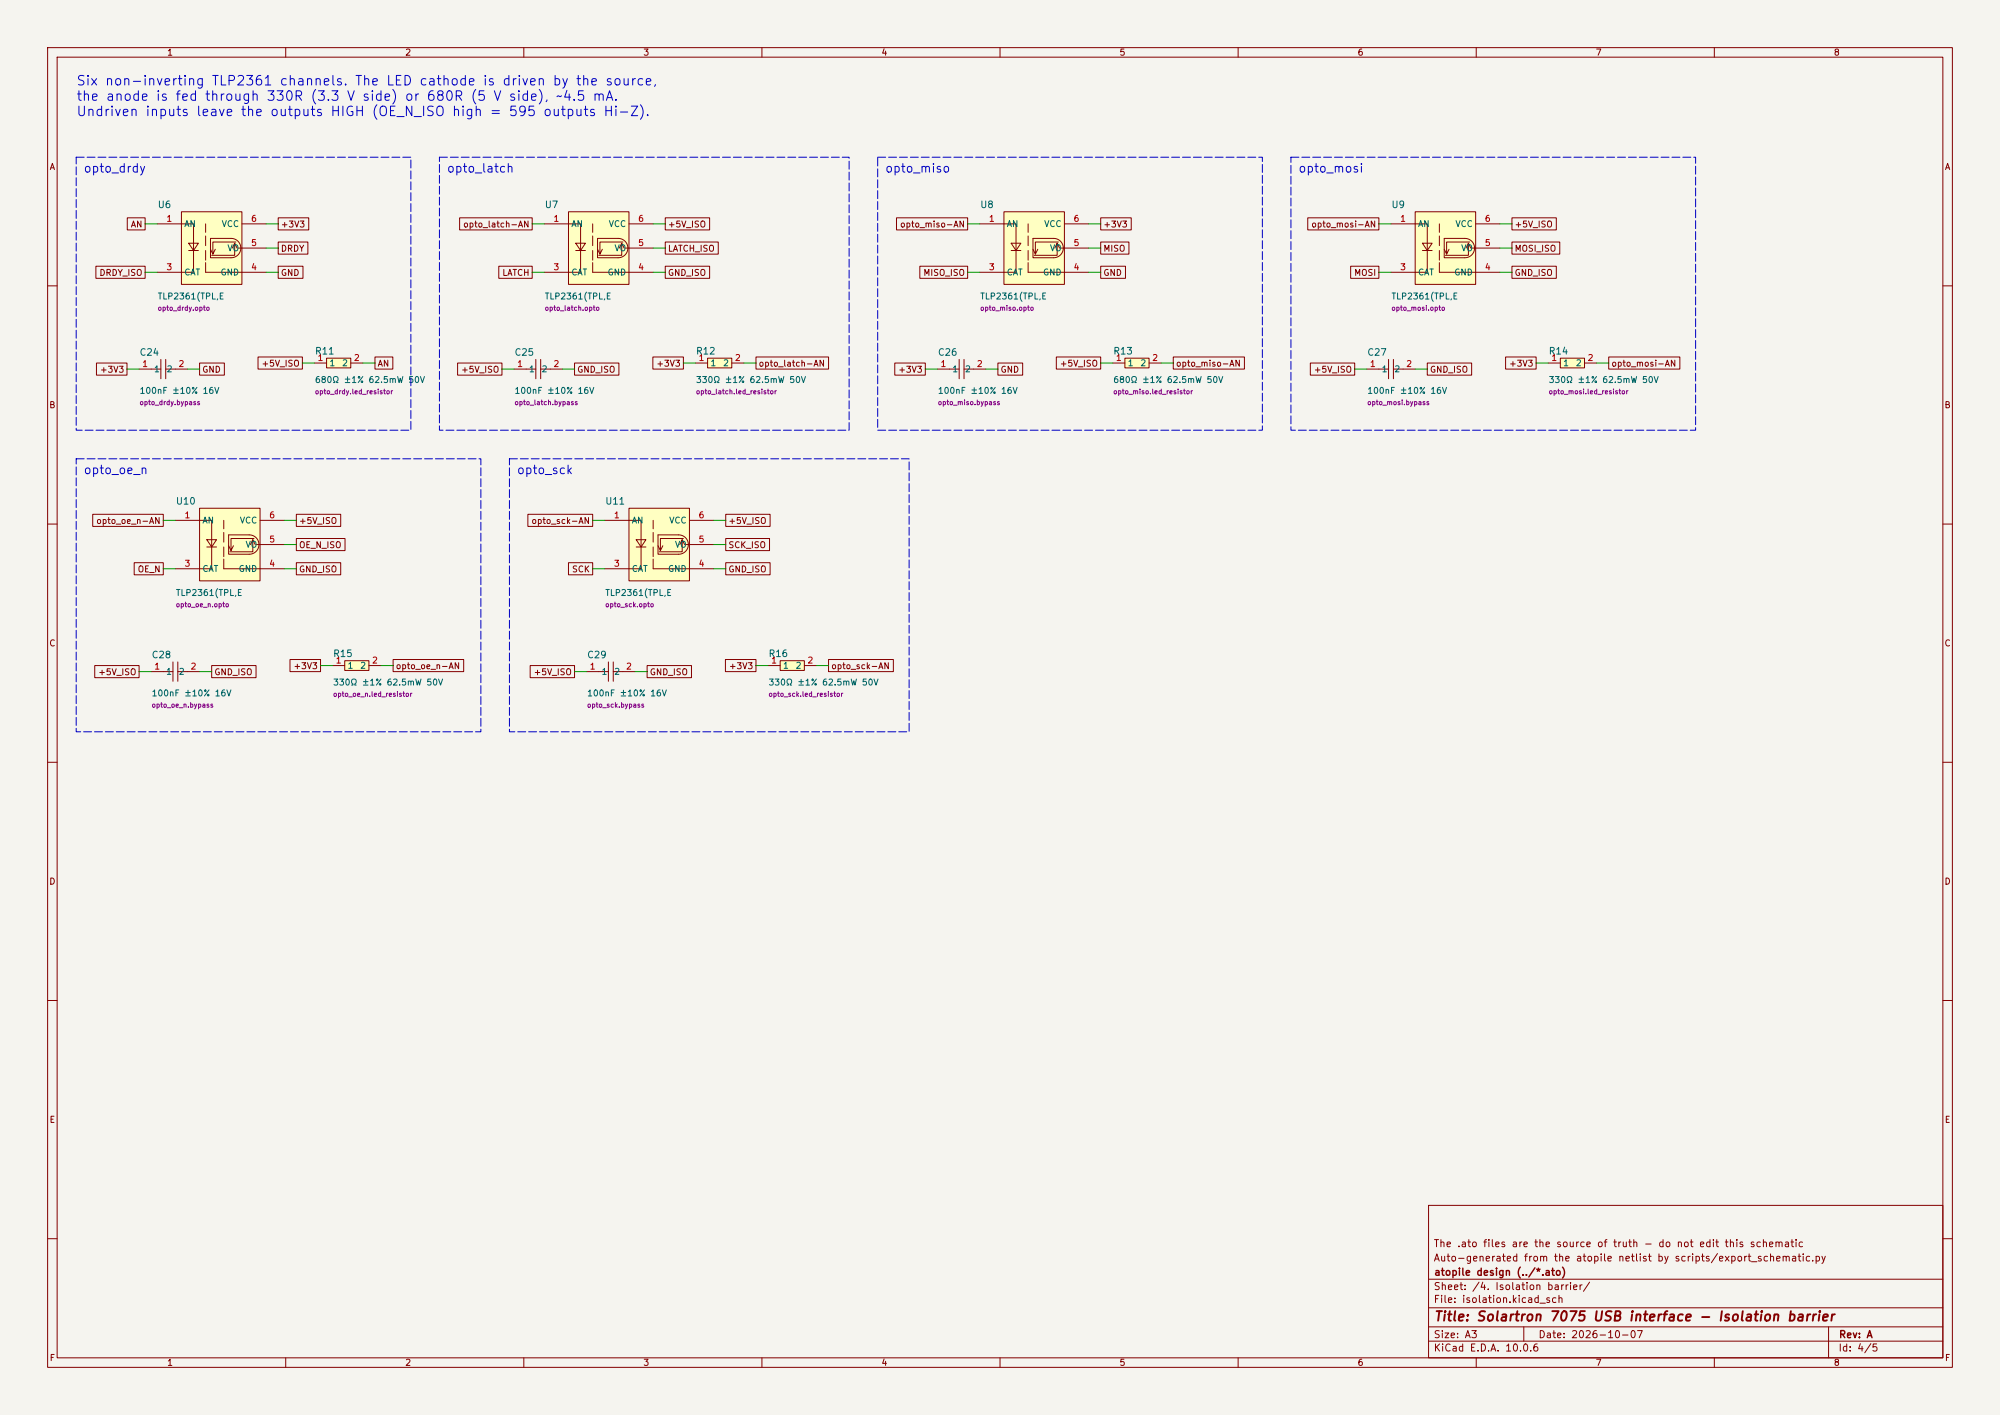
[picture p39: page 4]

GND_ISO Six non-inverting TLP2361 channels. The LED cathode is driven by the source,
the anode is fed through 330R (3.3 V side) or 680R (5 V side), ~4.5 mA.
Undriven inputs leave the outputs HIGH (OE_N_ISO high = 595 outputs Hi-Z).

The .ato files are the source of truth - do not edit this schematic
Auto-generated from the atopile netlist by scripts/export_schematic.py
atopile design (../*.ato)
Sheet: /4. Isolation barrier/
File: isolation.kicad_sch
Title: Solartron 7075 USB interface - Isolation barrier

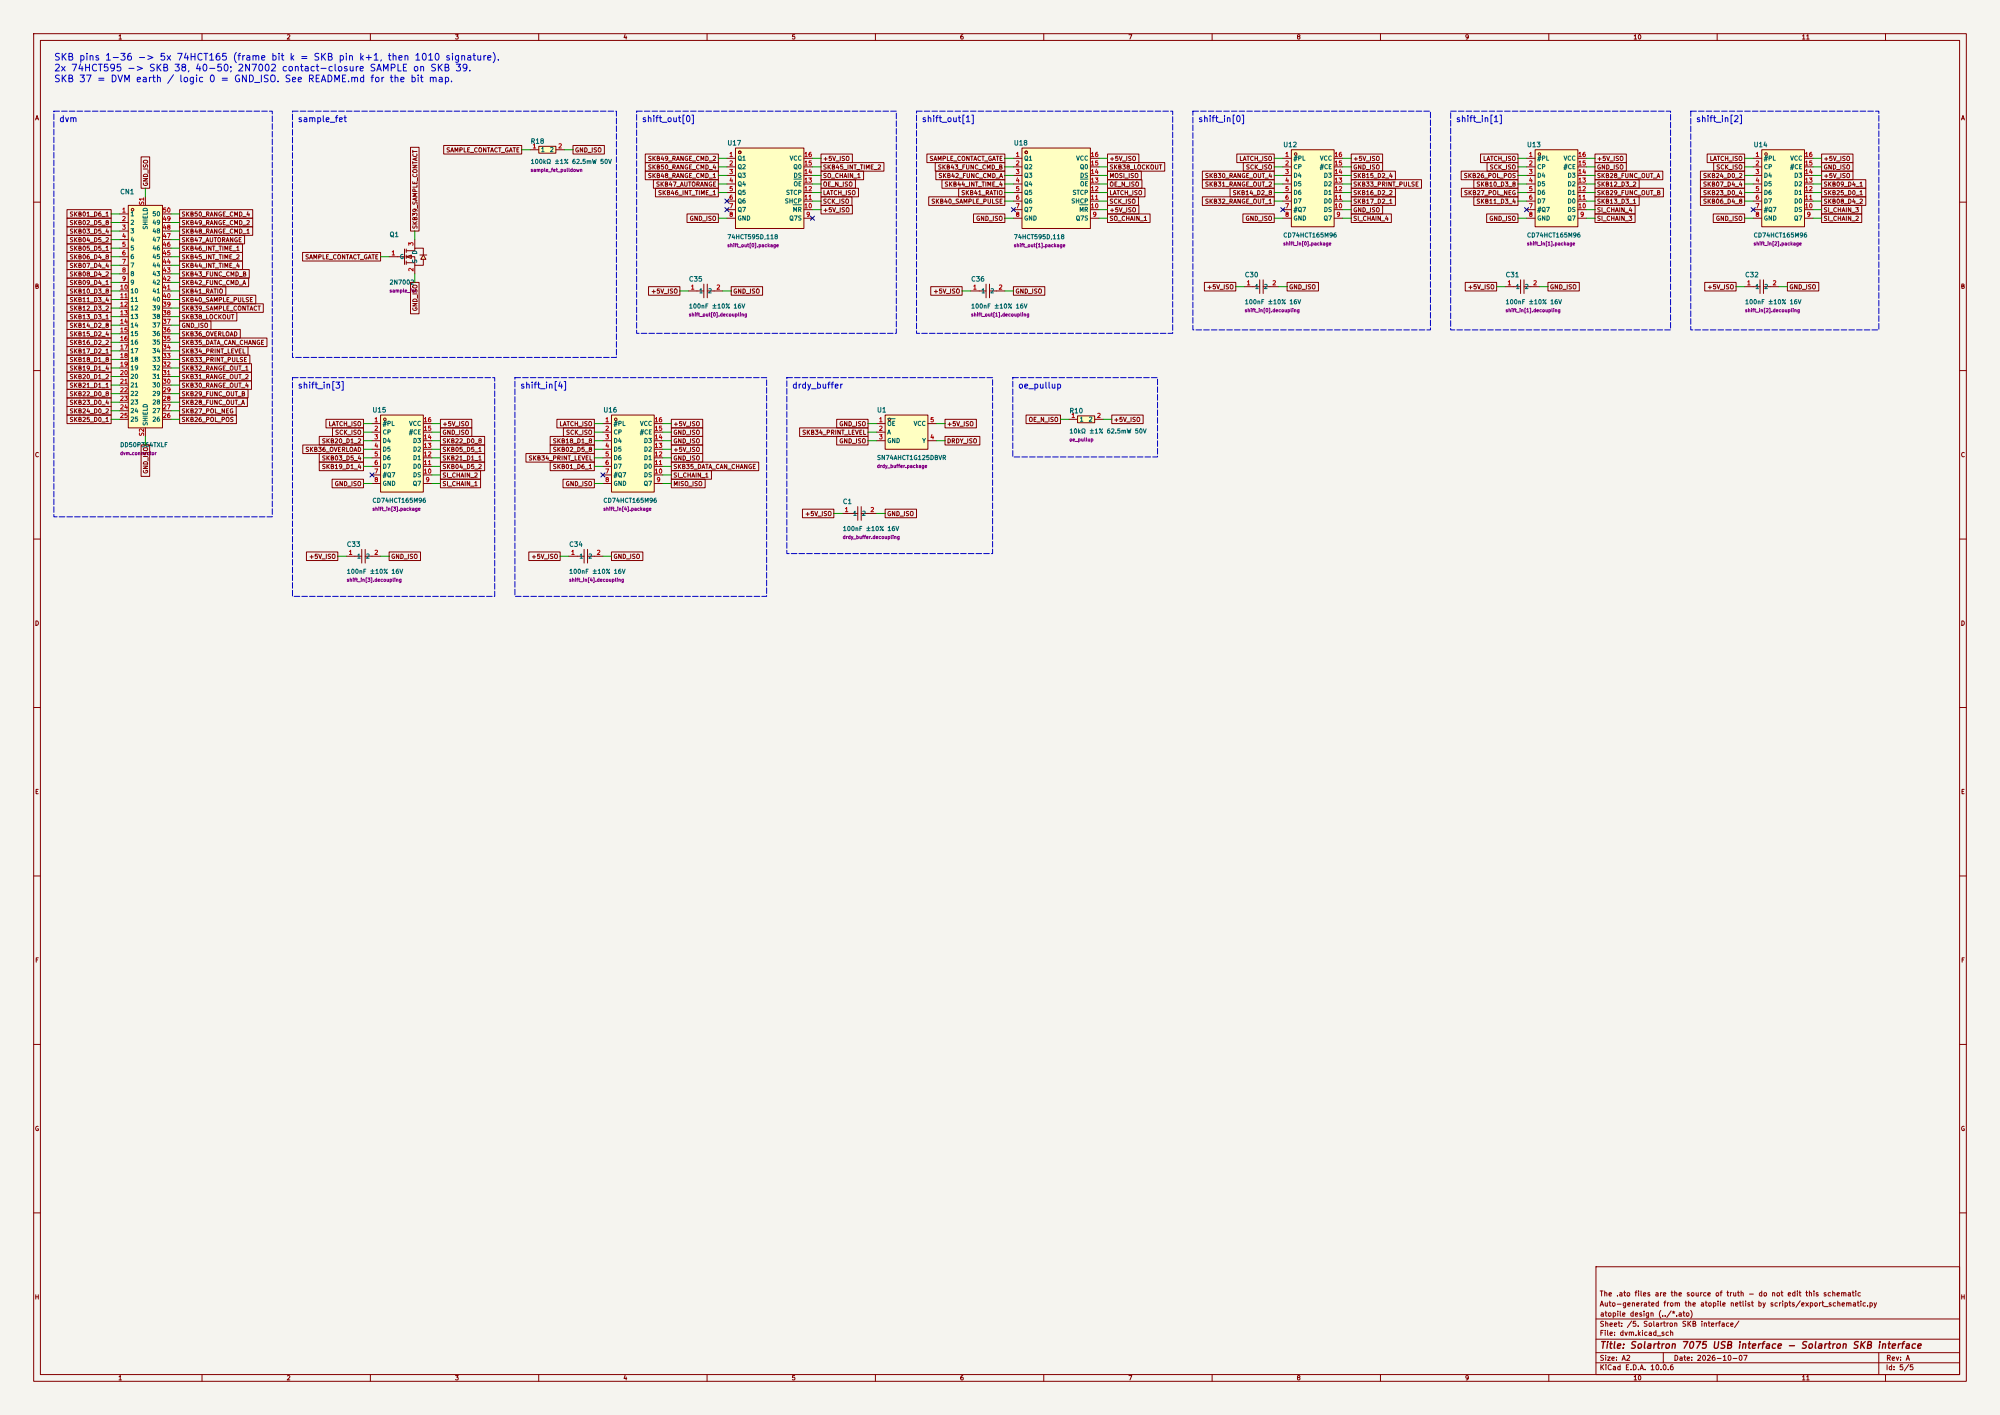
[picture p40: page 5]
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

The .ato files are the source of truth - do not edit this schematic
Auto-generated from the atopile netlist by scripts/export_schematic.py
atopile design (../*.ato)
Sheet: /5. Solartron SKB interface/
File: dvm.kicad_sch
Title: Solartron 7075 USB interface - Solartron SKB interface

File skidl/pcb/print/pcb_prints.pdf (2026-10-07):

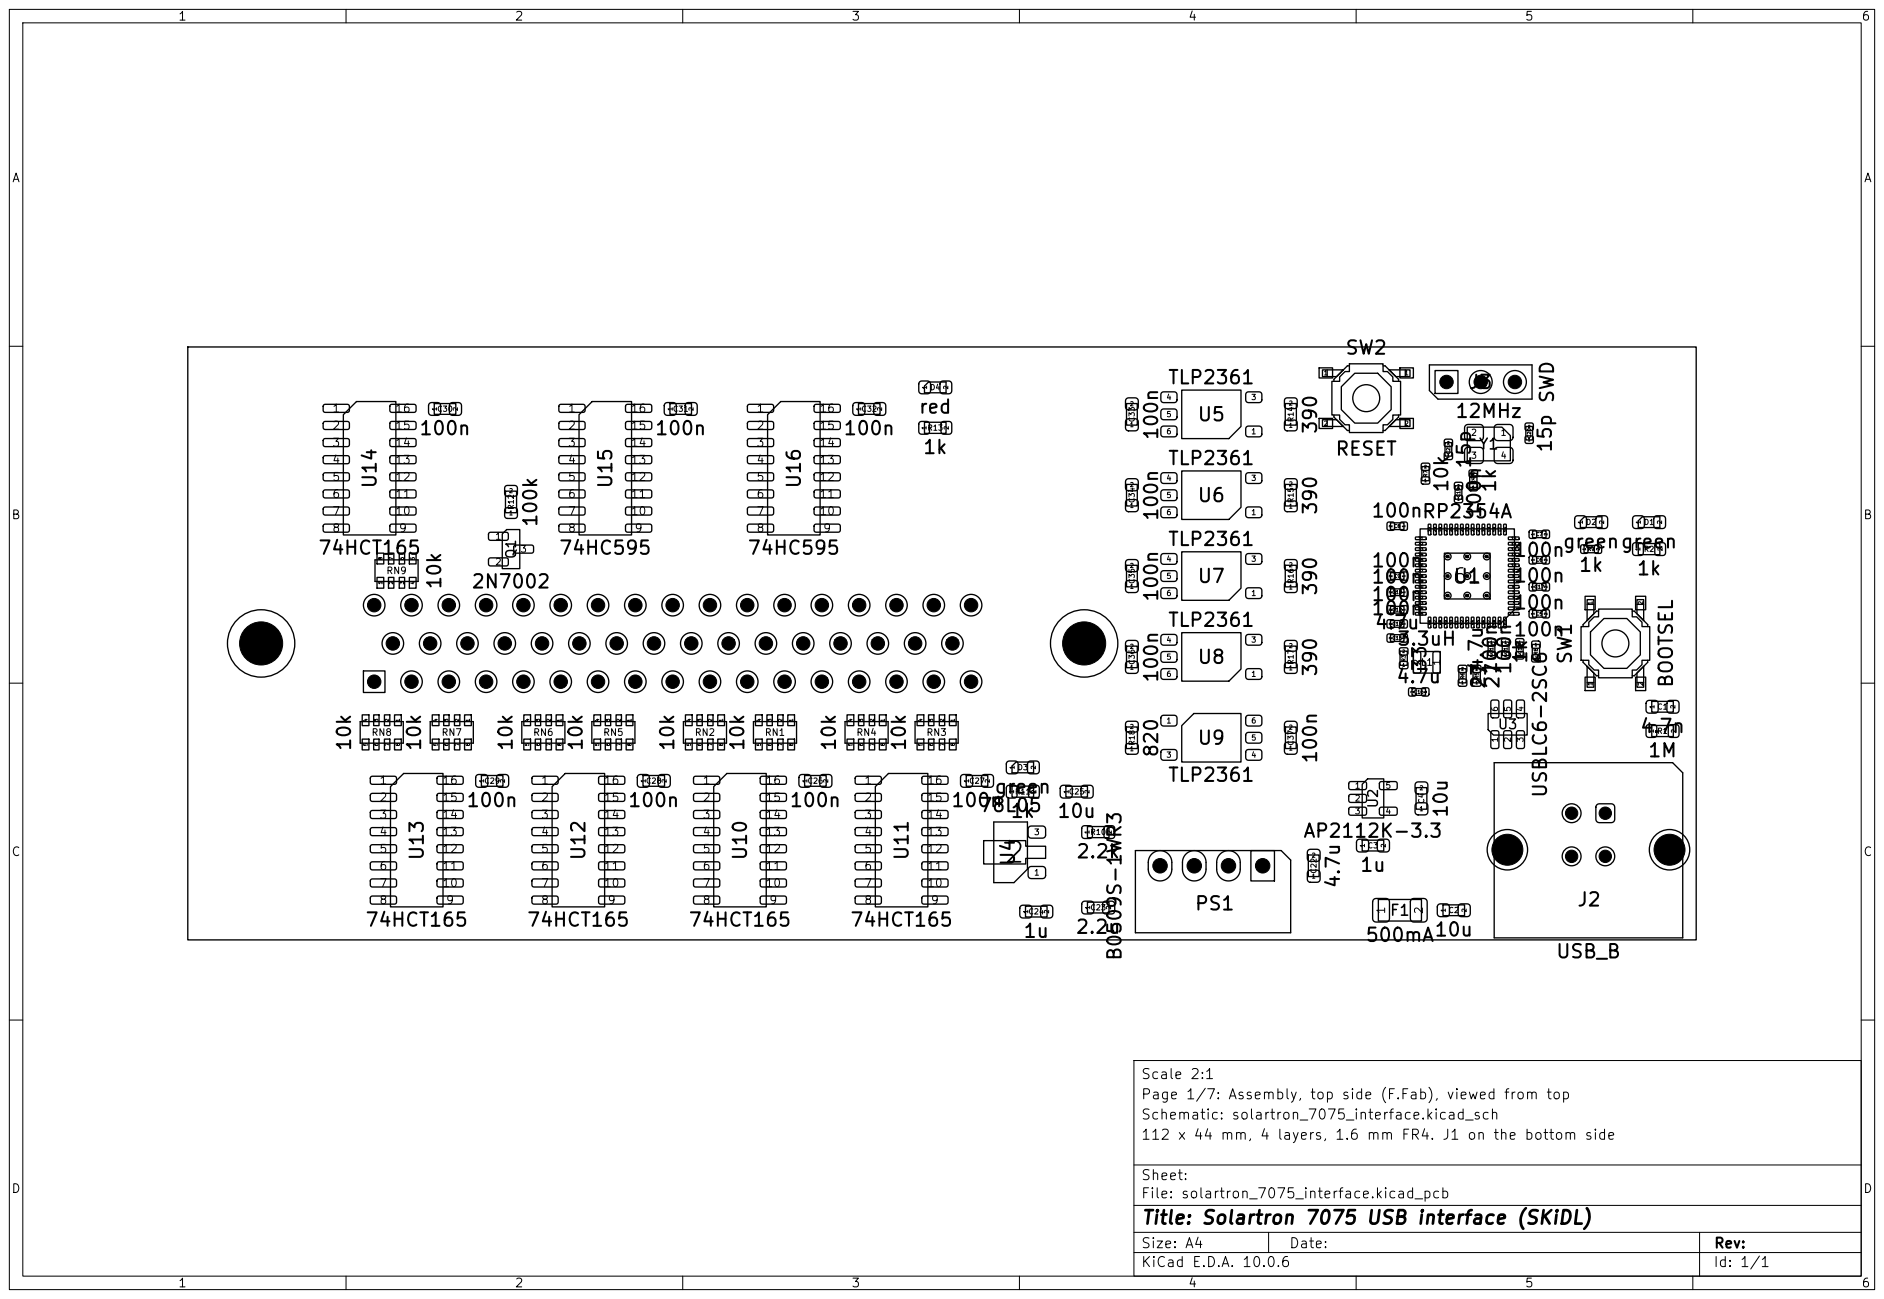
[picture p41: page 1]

Scale 2:1
Page 1/7: Assembly, top side (F.Fab), viewed from top
Schematic: solartron_7075_interface.kicad_sch
112 x 44 mm, 4 layers, 1.6 mm FR4. J1 on the bottom side

Sheet:
File: solartron_7075_interface.kicad_pcb
Title: Solartron 7075 USB interface (SKiDL)
KiCad E.D.A. 10.0.6

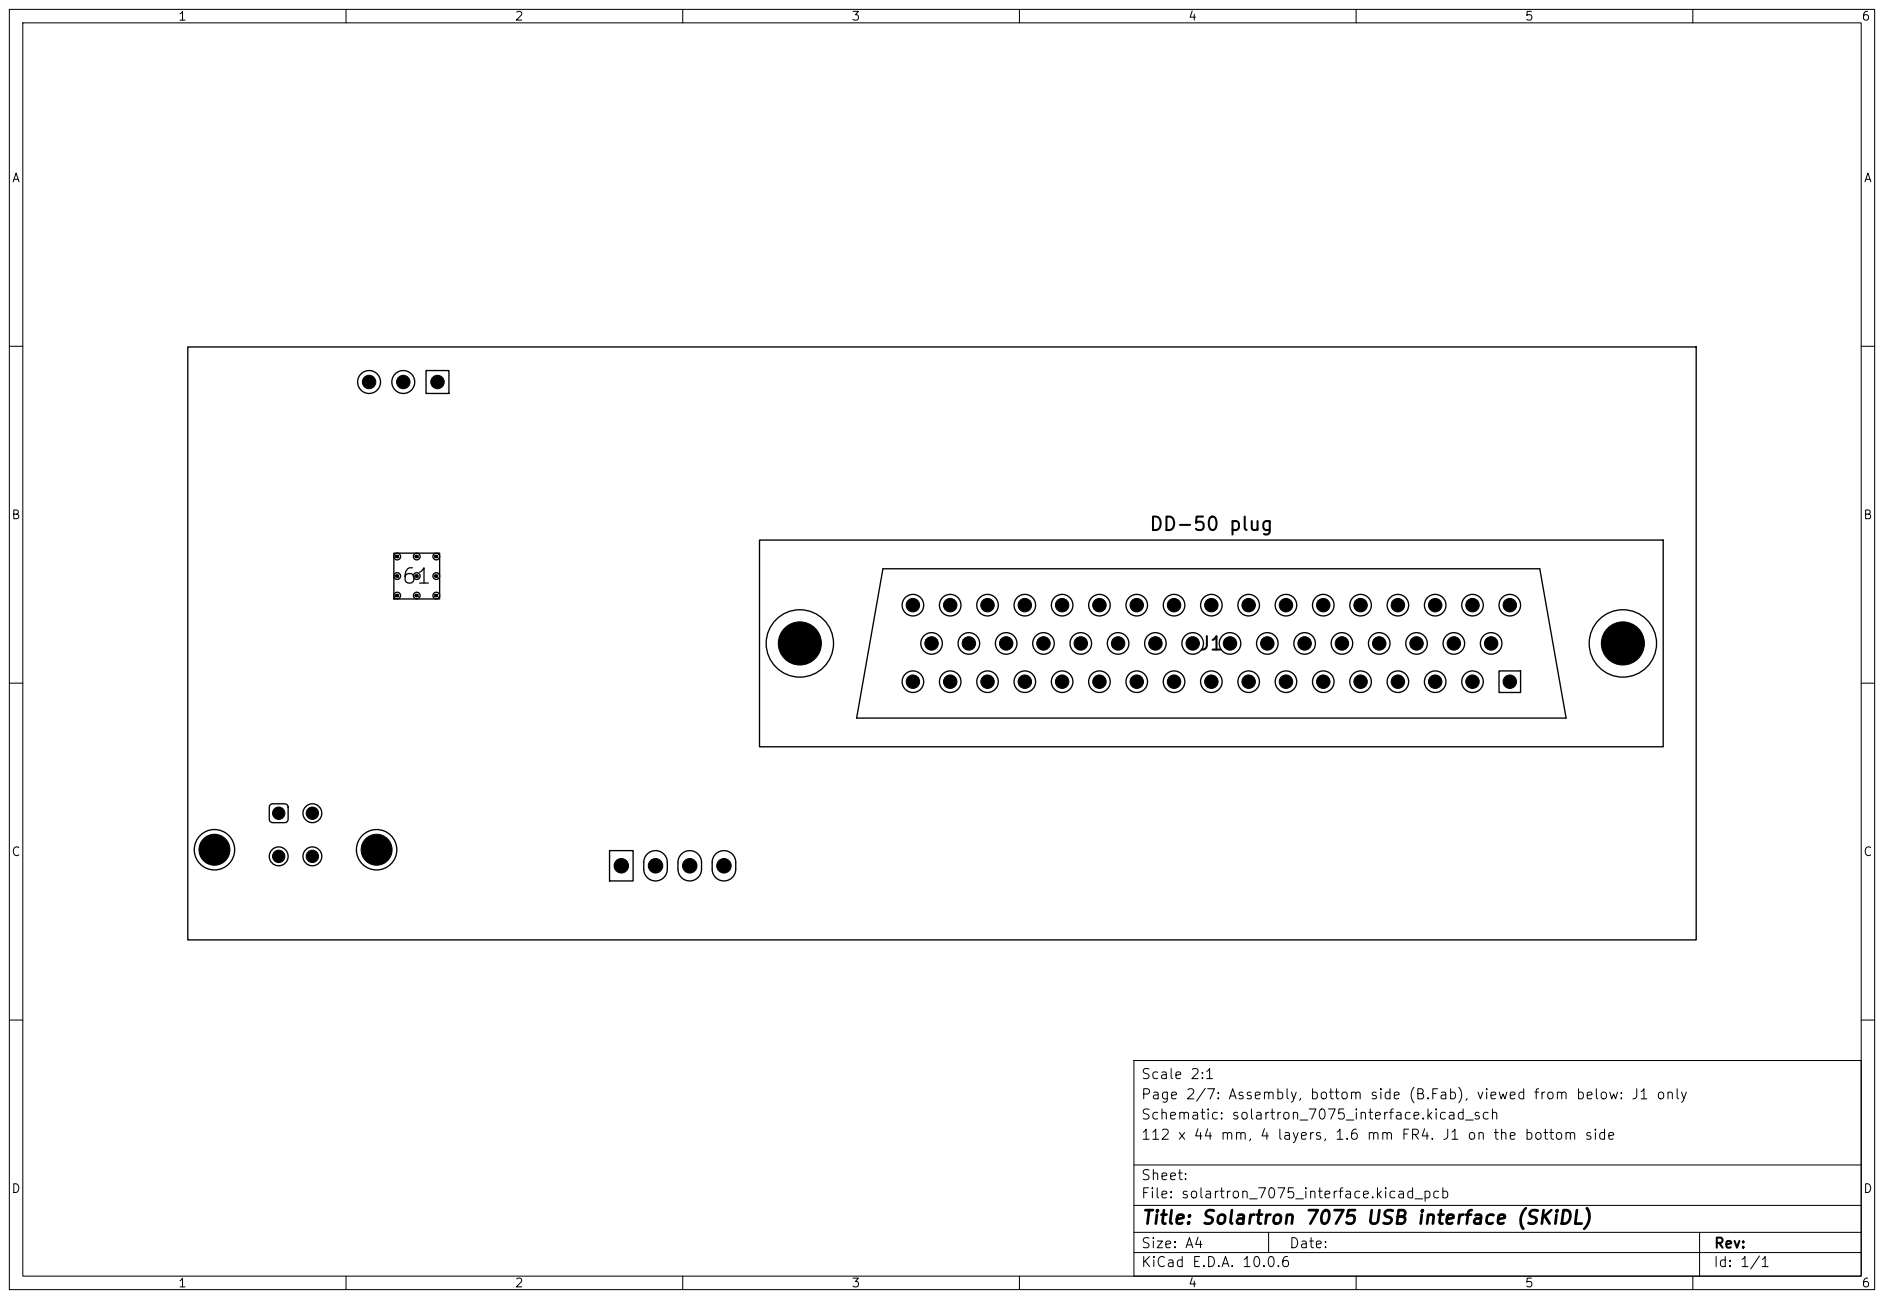
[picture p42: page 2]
D Date:; DD-50 plug

Scale 2:1
Page 2/7: Assembly, bottom side (B.Fab), viewed from below: J1 only
Schematic: solartron_7075_interface.kicad_sch
112 x 44 mm, 4 layers, 1.6 mm FR4. J1 on the bottom side

Sheet:
File: solartron_7075_interface.kicad_pcb
Title: Solartron 7075 USB interface (SKiDL)

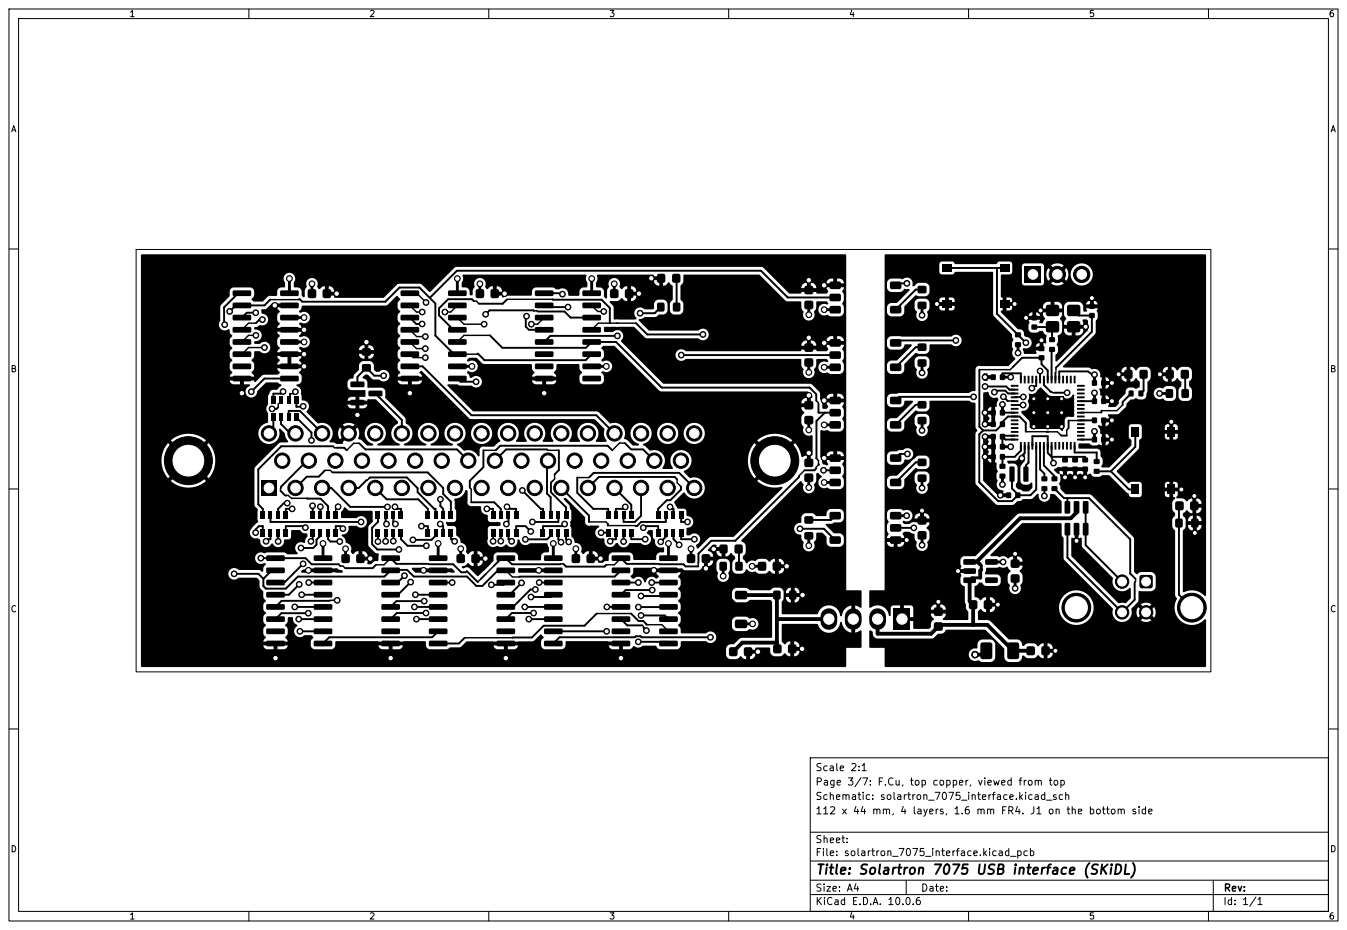
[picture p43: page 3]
D Date:

Scale 2:1
Page 3/7: F.Cu, top copper, viewed from top
Schematic: solartron_7075_interface.kicad_sch
112 x 44 mm, 4 layers, 1.6 mm FR4. J1 on the bottom side

Sheet:
File: solartron_7075_interface.kicad_pcb
Title: Solartron 7075 USB interface (SKiDL)

D Date:

Scale 2:1
Page 4/7: In1.Cu, ISO_GND (left) / GND (right) planes, viewed from top
Schematic: solartron_7075_interface.kicad_sch
112 x 44 mm, 4 layers, 1.6 mm FR4. J1 on the bottom side

Sheet:
File: solartron_7075_interface.kicad_pcb
Title: Solartron 7075 USB interface (SKiDL)

D Date:

Scale 2:1
Page 5/7: In2.Cu, ISO_+5V (left) / +3V3 (right) planes, viewed from top
Schematic: solartron_7075_interface.kicad_sch
112 x 44 mm, 4 layers, 1.6 mm FR4. J1 on the bottom side

Sheet:
File: solartron_7075_interface.kicad_pcb
Title: Solartron 7075 USB interface (SKiDL)

D Date:

Scale 2:1
Page 6/7: B.Cu, bottom copper, viewed from below
Schematic: solartron_7075_interface.kicad_sch
112 x 44 mm, 4 layers, 1.6 mm FR4. J1 on the bottom side

Sheet:
File: solartron_7075_interface.kicad_pcb
Title: Solartron 7075 USB interface (SKiDL)

D Date:; DD-50 plug

4-40 UNC JACKSCREWS J1 TO 7075 SKB

Scale 1:1
Page 7/7: FIT CHECK 1:1 - print at 100 %, viewed from the meter side (below)
Schematic: solartron_7075_interface.kicad_sch
112 x 44 mm, 4 layers, 1.6 mm FR4. J1 on the bottom side

Sheet:
File: solartron_7075_interface.kicad_pcb
Title: Solartron 7075 USB interface (SKiDL)

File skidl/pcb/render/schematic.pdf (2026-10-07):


Isolated serial link (RP2354A SPI0 / PIO): SPI mode 0, MSB first, <= 1 MHz, 40 clocks per transfer.
Pulse LATCH low >= 1 us, then clock 5 bytes. LATCH low: the 74HCT165s sample the meter outputs.
LATCH rising edge: the 74HC595 outputs take the last two bytes clocked in.
QSPI_SS POL_POS
/OE (GPIO24) high = command outputs off (the default while the MCU is unpowered or in reset).
MISO byte0 U10: POL+ POL- FUNC_A FUNC_B RANGE_4 RANGE_2 RANGE_1 PRINT_PULSE

Meter levels (7075 manual sect. 9): outputs '1' = 2.4..6 V from 6k, '0' sinks 10 mA;
inputs '1' = 2.4..5 V, '0' < 0.5 V at 5 mA. Series 10k on every meter output.
ISO_GND = SKB pin 37 (meter earth / logic 0). Net labels of the same name are connected.

DISPLAY DATA / STATUS INPUTS: 5 x 74HCT165 (MISO = U10.Q7; chain U10 <- U11 <- U12 <- U13 <- U14)

Net labels with the same name are connected
Generated from the SKiDL netlist by scripts/gen_schematic.py

Sheet: /
File: solartron_7075_interface.kicad_sch
Title: Solartron 7075 USB interface (SKiDL)

Size: A2 | Rev:
KiCad E.D.A. 10.0.6 | Id: 1/1

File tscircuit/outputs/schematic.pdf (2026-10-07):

BF 180

J1


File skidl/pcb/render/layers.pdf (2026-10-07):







JACKSCREWS UNC 4-40 SKB 7075 TO J1

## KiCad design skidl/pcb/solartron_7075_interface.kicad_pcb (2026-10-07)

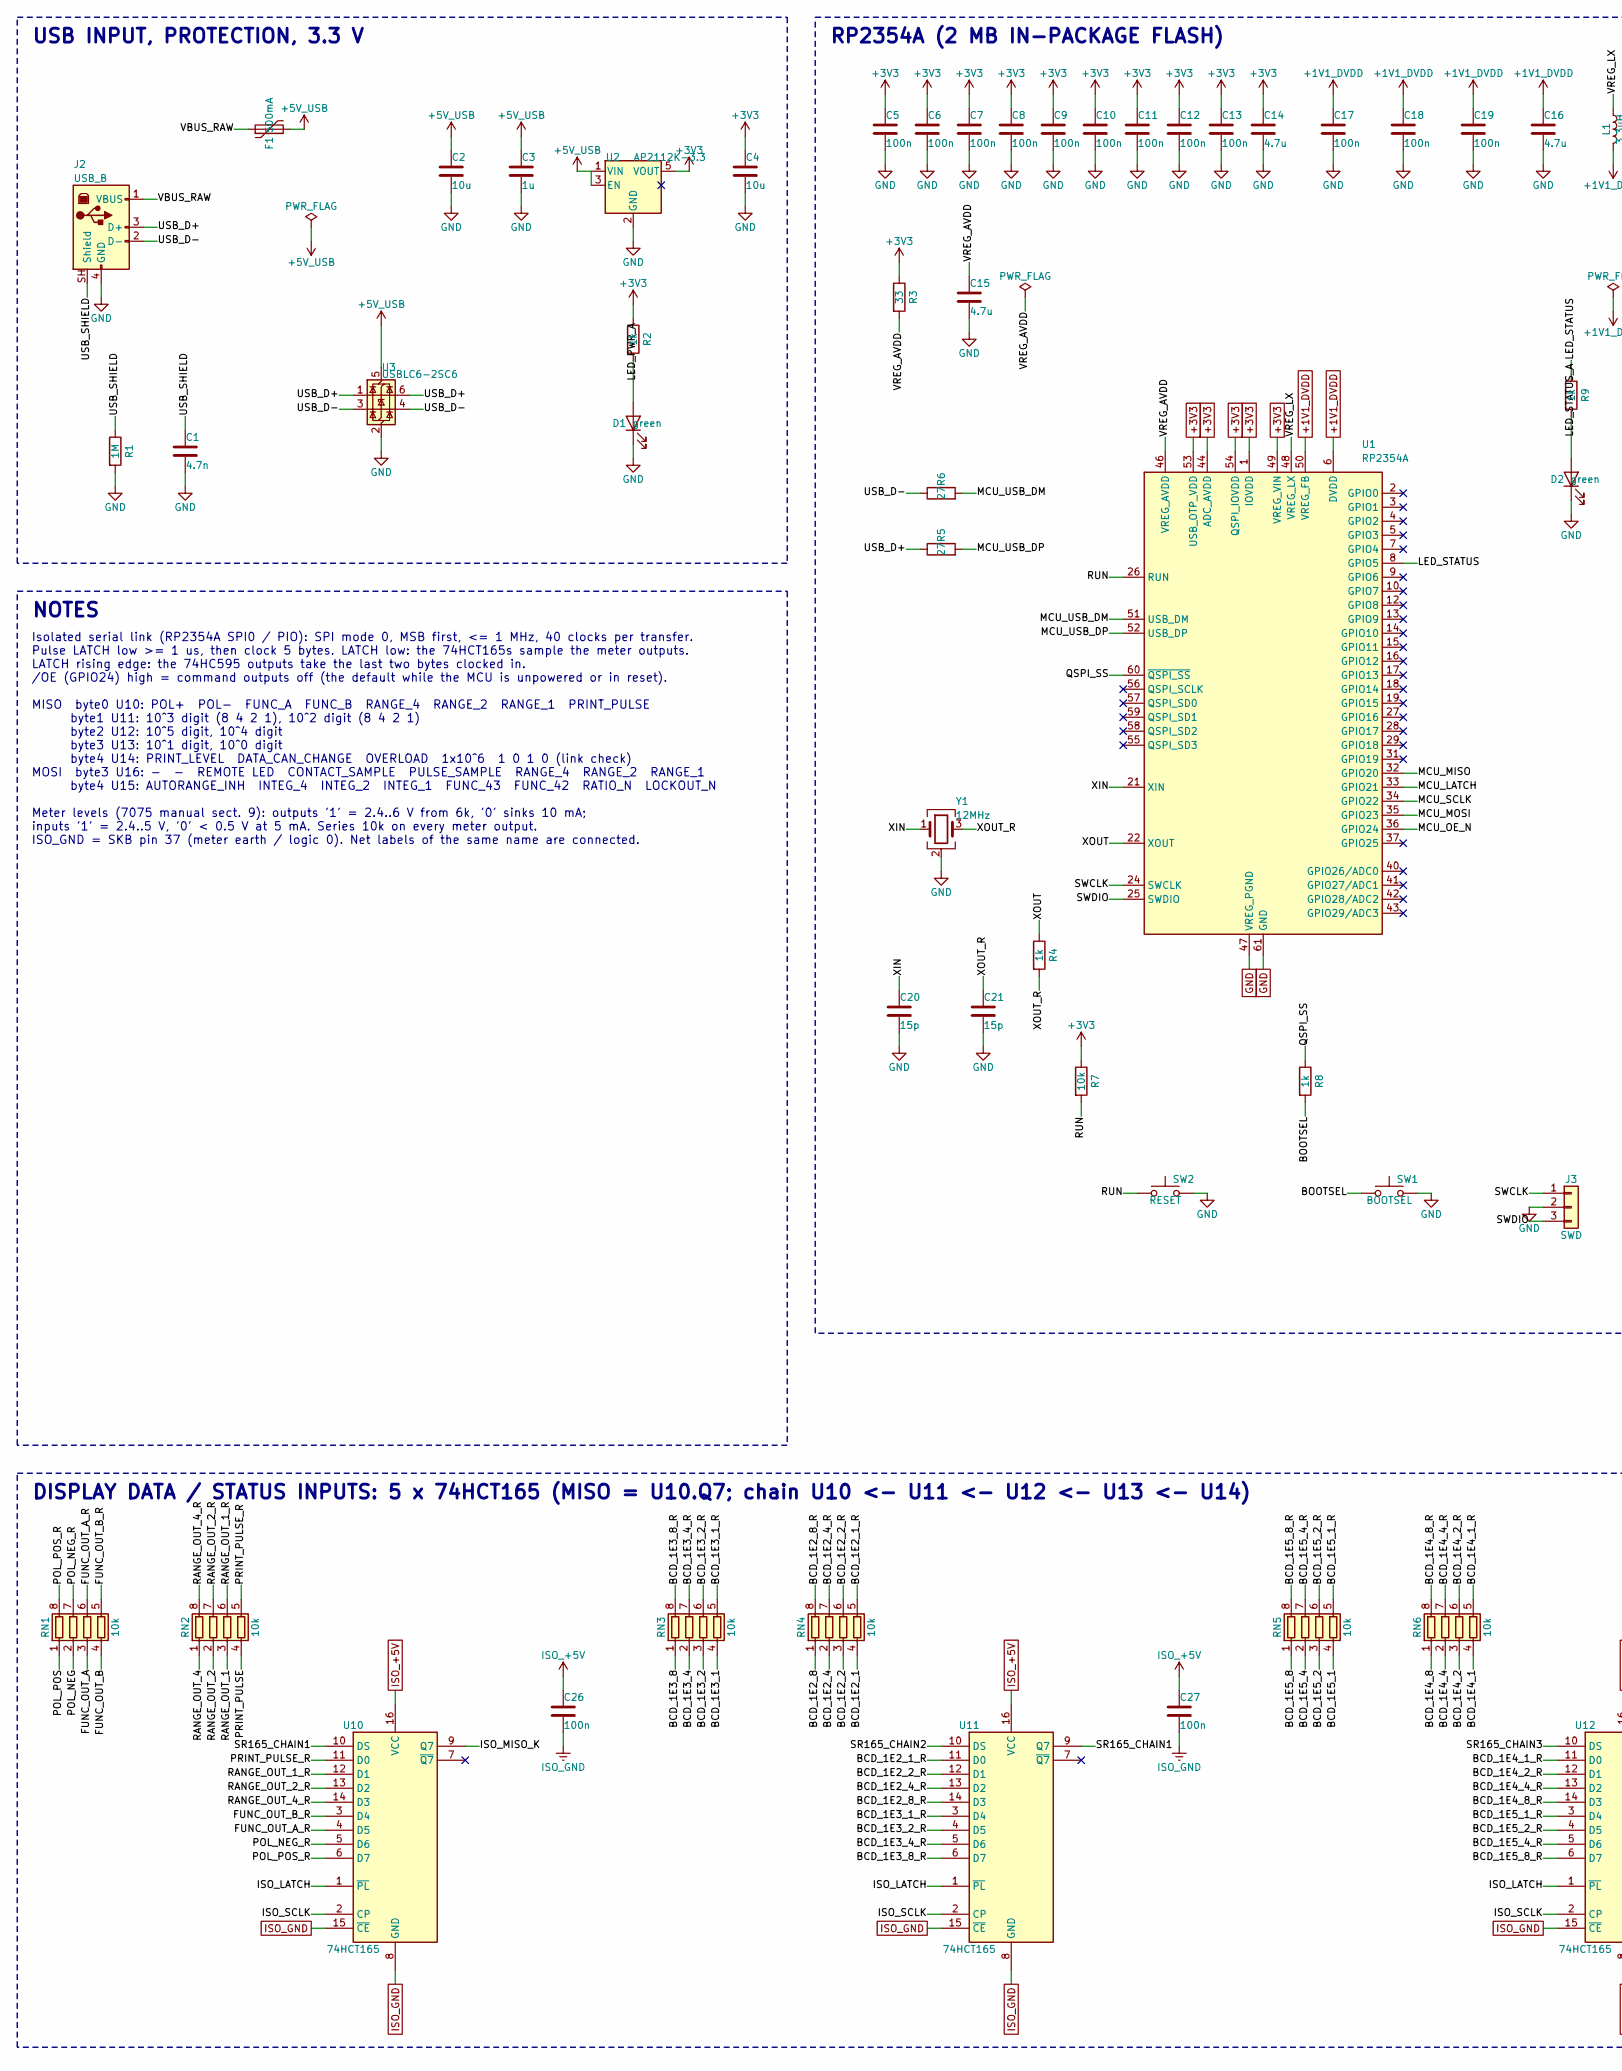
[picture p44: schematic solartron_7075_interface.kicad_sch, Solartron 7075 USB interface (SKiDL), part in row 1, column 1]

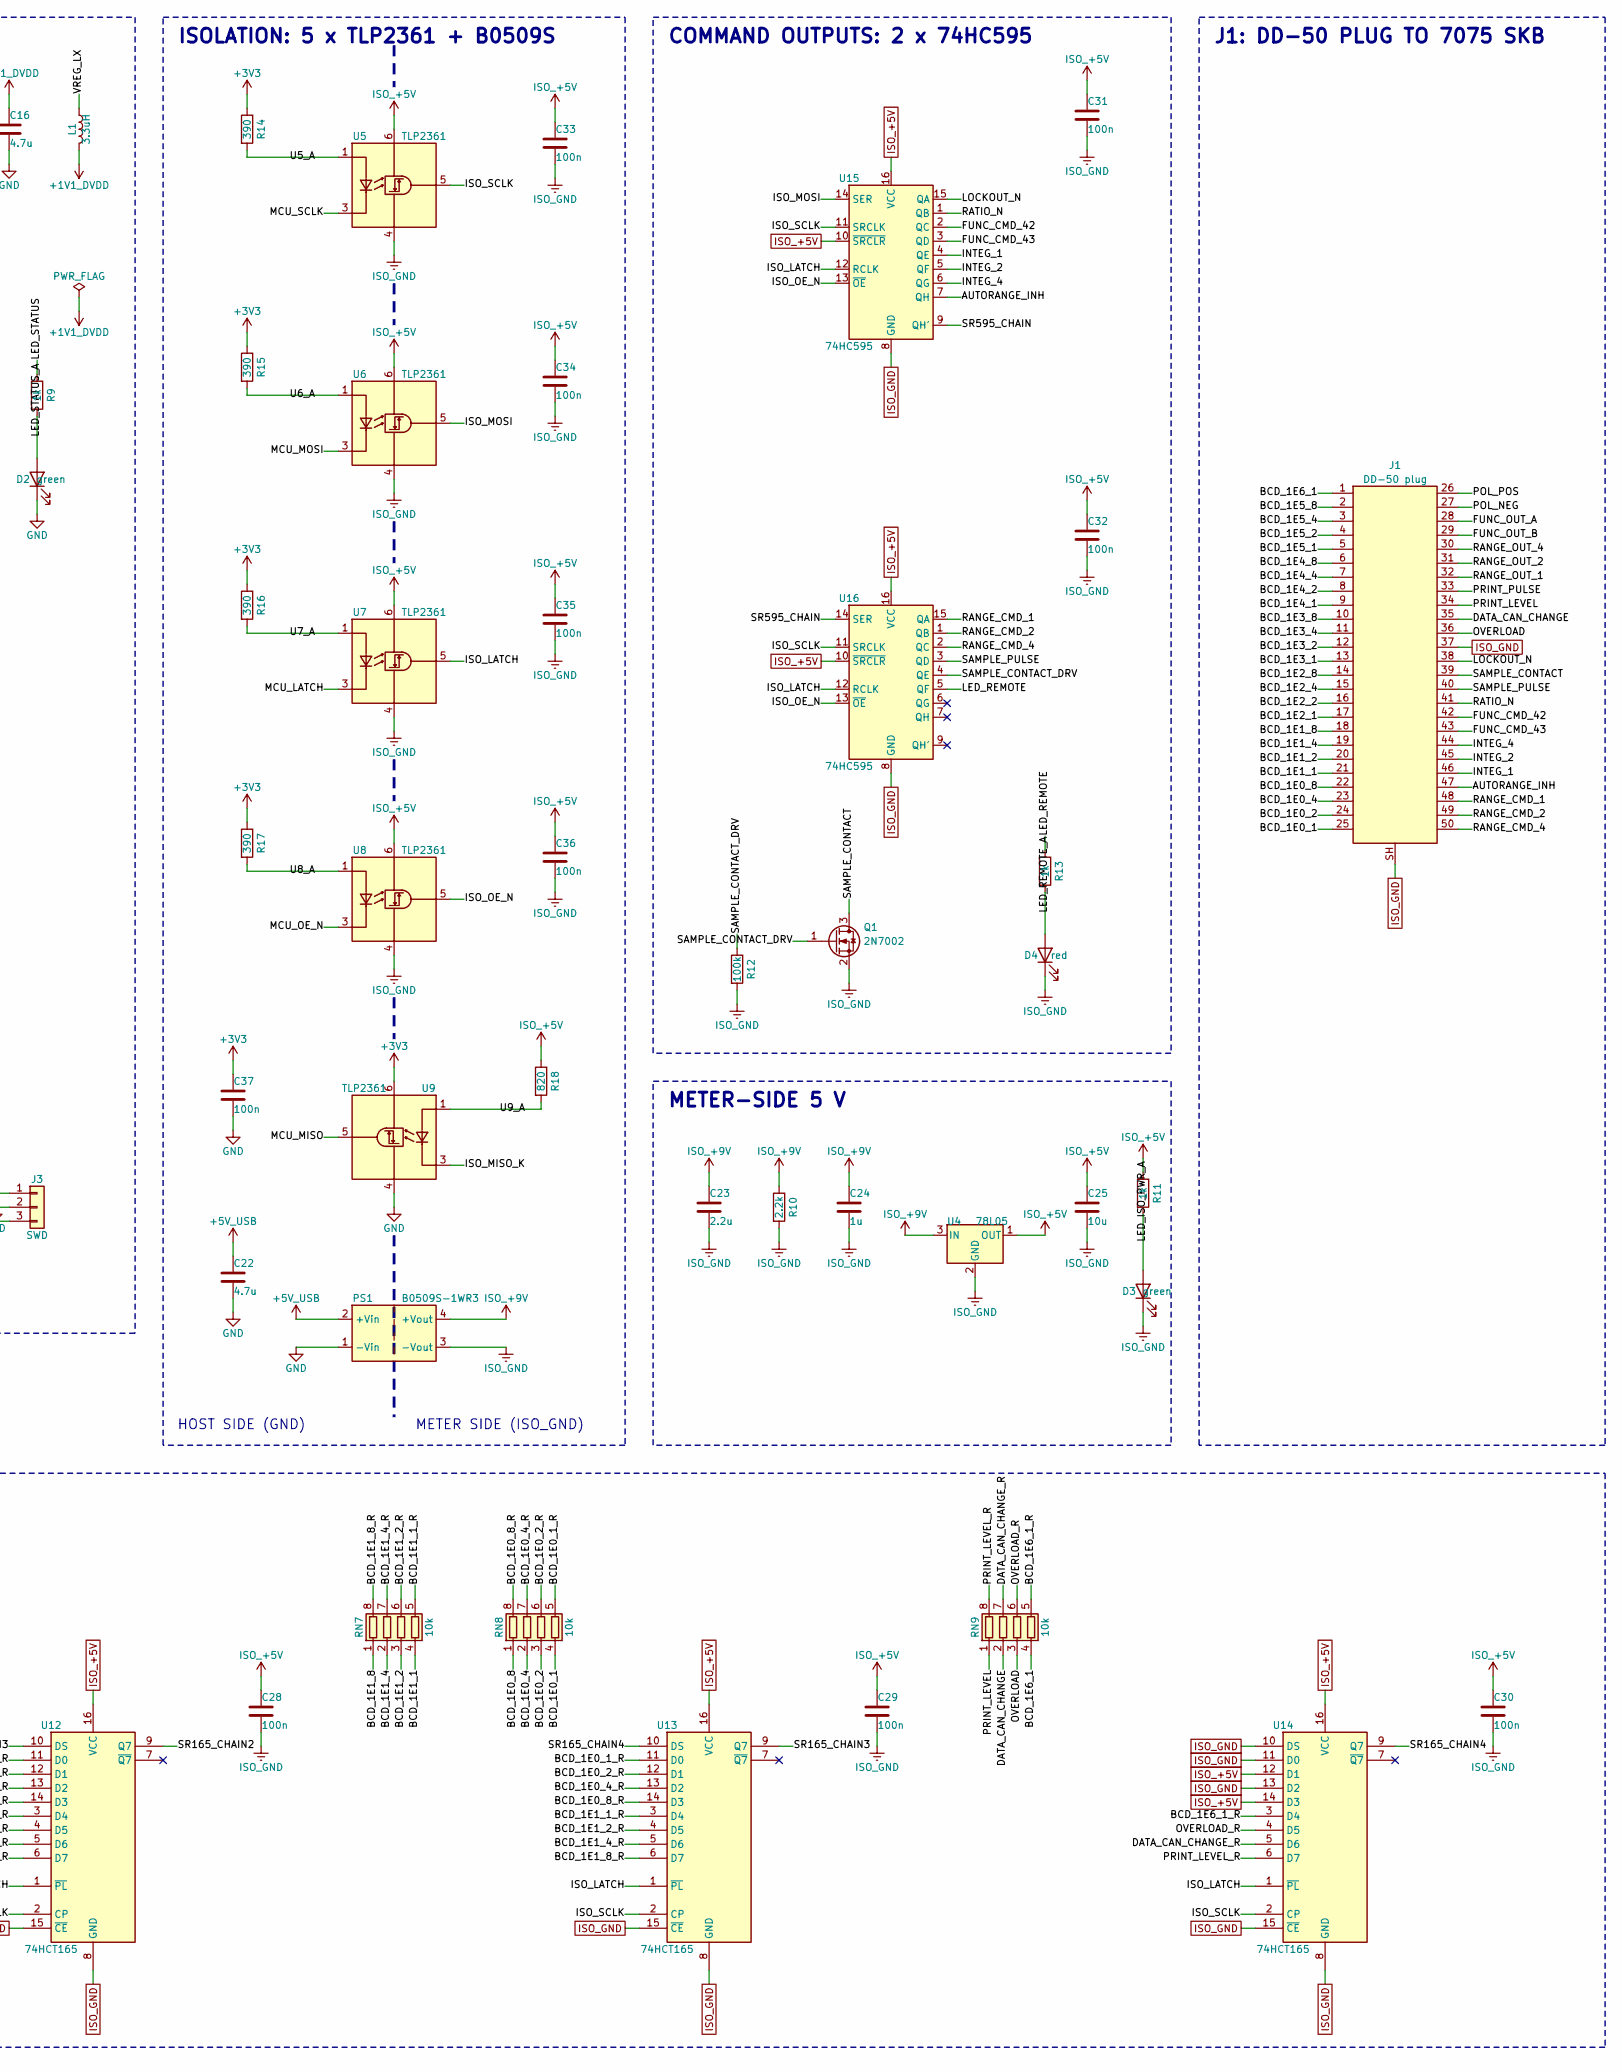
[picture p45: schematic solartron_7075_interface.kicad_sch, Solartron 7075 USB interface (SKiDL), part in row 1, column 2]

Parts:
C1: 4.7n; C_0603_1608Metric; MPN 0603B472K500NT; LCSC C53987
C2, C4, C25: 10u; C_0603_1608Metric; MPN CL10A106KP8NNNC; LCSC C19702
C3, C24: 1u; C_0603_1608Metric; MPN CL10A105KB8NNNC; LCSC C15849
C5, C6, C7, C8, C9, C10, C11, C12, C13, C17, C18, C19: 100n; C_0402_1005Metric; MPN CL05B104KO5NNNC; LCSC C1525
C14, C15, C16: 4.7u; C_0402_1005Metric; MPN CL05A475MP5NRNC; LCSC C23733
C20, C21: 15p; C_0402_1005Metric; MPN 0402CG150J500NT; LCSC C1548
C22: 4.7u; C_0603_1608Metric; MPN CL10A475KO8NNNC; LCSC C19666
C23: 2.2u; C_0603_1608Metric; MPN CL10A225KO8NNNC; LCSC C23630
C26, C27, C28, C29, C30, C31, C32, C33, C34, C35, C36, C37: 100n; C_0603_1608Metric; MPN CC0603KRX7R9BB104; LCSC C14663
D1, D2, D3: green; LED_0603_1608Metric; MPN LTST-C190KGKT; LCSC C125094
D4: red; LED_0603_1608Metric; MPN KT-0603R; LCSC C2286
F1: 500mA; Fuse_1206_3216Metric; MPN SMD1206P050TF; LCSC C20799
J1: DD-50 plug; DSUB-50_Pins_Vertical_P2.77x2.84mm_MountingHoles; MPN D50P24A4PA00LF; LCSC C17502305
J2: USB_B; USB_B_TE_5787834_Vertical; MPN 5787834-1; LCSC C592900
J3: SWD; PinHeader_1x03_P2.54mm_Vertical; MPN PZ254V-11-03P; LCSC C2937625
L1: 3.3uH; L_Murata_DFE201610P; MPN AOTA-B201610S3R3-101-T; LCSC C42411119
PS1: B0509S-1WR3; Converter_DCDC_Murata_MEE1SxxxxSC_THT; MPN B0509S-1WR3; LCSC C7500906
Q1: 2N7002; SOT-23; MPN 2N7002; LCSC C8545
R1: 1M; R_0603_1608Metric; MPN 0603WAF1004T5E; LCSC C22935
R2, R11, R13: 1k; R_0603_1608Metric; MPN 0603WAF1001T5E; LCSC C21190
R3: 33; R_0402_1005Metric; MPN 0402WGF330JTCE; LCSC C25105
R4, R8, R9: 1k; R_0402_1005Metric; MPN 0402WGF1001TCE; LCSC C11702
R5, R6: 27; R_0402_1005Metric; MPN 0402WGF270JTCE; LCSC C25100
R7: 10k; R_0402_1005Metric; MPN 0402WGF1002TCE; LCSC C25744
R10: 2.2k; R_0603_1608Metric; MPN 0603WAF2201T5E; LCSC C4190
R12: 100k; R_0603_1608Metric; MPN 0603WAF1003T5E; LCSC C25803
R14, R15, R16, R17: 390; R_0603_1608Metric; MPN 0603WAF3900T5E; LCSC C23151
R18: 820; R_0603_1608Metric; MPN 0603WAF8200T5E; LCSC C23253
RN1, RN2, RN3, RN4, RN5, RN6, RN7, RN8, RN9: 10k; R_Array_Convex_4x0603; MPN 4D03WGJ0103T5E; LCSC C29718
SW1: BOOTSEL; SW_Push_1P1T_XKB_TS-1187A; MPN TS-1187A-B-A-B; LCSC C318884
SW2: RESET; SW_Push_1P1T_XKB_TS-1187A; MPN TS-1187A-B-A-B; LCSC C318884
U1: RP2354A; QFN-60-1EP_7x7mm_P0.4mm_EP3.4x3.4mm_ThermalVias; MPN RP2354A; LCSC C41378174
U2: AP2112K-3.3; SOT-23-5; MPN AP2112K-3.3TRG1; LCSC C51118
U3: USBLC6-2SC6; SOT-23-6; MPN USBLC6-2SC6; LCSC C7519
U4: 78L05; SOT-89-3; MPN 78L05 (SOT-89); LCSC C347258
U5, U6, U7, U8, U9: TLP2361; Toshiba_SOIC-5-6_4.4x3.6mm_P1.27mm; MPN TLP2361(TPL,E; LCSC C107626
U10, U11, U12, U13, U14: 74HCT165; SOIC-16_3.9x9.9mm_P1.27mm; MPN 74HCT165D,653; LCSC C456131
U15, U16: 74HC595; SOIC-16_3.9x9.9mm_P1.27mm; MPN 74HC595D,118; LCSC C5947
Y1: 12MHz; Crystal_SMD_3225-4Pin_3.2x2.5mm; MPN ABM8-272-T3; LCSC C20625731

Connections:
+1V1_DVDD: C16.1, C17.1, C18.1, C19.1, L1.2, U1.6 (DVDD), U1.23 (DVDD), U1.39 (DVDD), U1.50 (VREG_FB)
+3V3: C4.1, C5.1, C6.1, C7.1, C8.1, C9.1, C10.1, C11.1, C12.1, C13.1, C14.1, C37.1, R2.1, R3.1, R7.1, R14.1, R15.1, R16.1, R17.1, U1.1 (IOVDD), U1.11 (IOVDD), U1.20 (IOVDD), U1.30 (IOVDD), U1.38 (IOVDD), U1.44 (ADC_AVDD), U1.45 (IOVDD), U1.49 (VREG_VIN), U1.53 (USB_OTP_VDD), U1.54 (QSPI_IOVDD), U2.5 (VOUT), U9.6 (VDD)
+5V_USB: C2.1, C3.1, C22.1, F1.2, PS1.2 (+Vin), U2.1 (VIN), U2.3 (EN), U3.5 (VBUS)
/AUTORANGE_INH: J1.47, U15.7 (QH)
/BCD_1E0_1: J1.25, RN8.4 (R4.1)
/BCD_1E0_1_R: RN8.5 (R4.2), U13.11 (D0)
/BCD_1E0_2: J1.24, RN8.3 (R3.1)
/BCD_1E0_2_R: RN8.6 (R3.2), U13.12 (D1)
/BCD_1E0_4: J1.23, RN8.2 (R2.1)
/BCD_1E0_4_R: RN8.7 (R2.2), U13.13 (D2)
/BCD_1E0_8: J1.22, RN8.1 (R1.1)
/BCD_1E0_8_R: RN8.8 (R1.2), U13.14 (D3)
/BCD_1E1_1: J1.21, RN7.4 (R4.1)
/BCD_1E1_1_R: RN7.5 (R4.2), U13.3 (D4)
/BCD_1E1_2: J1.20, RN7.3 (R3.1)
/BCD_1E1_2_R: RN7.6 (R3.2), U13.4 (D5)
/BCD_1E1_4: J1.19, RN7.2 (R2.1)
/BCD_1E1_4_R: RN7.7 (R2.2), U13.5 (D6)
/BCD_1E1_8: J1.18, RN7.1 (R1.1)
/BCD_1E1_8_R: RN7.8 (R1.2), U13.6 (D7)
/BCD_1E2_1: J1.17, RN4.4 (R4.1)
/BCD_1E2_1_R: RN4.5 (R4.2), U11.11 (D0)
/BCD_1E2_2: J1.16, RN4.3 (R3.1)
/BCD_1E2_2_R: RN4.6 (R3.2), U11.12 (D1)
/BCD_1E2_4: J1.15, RN4.2 (R2.1)
/BCD_1E2_4_R: RN4.7 (R2.2), U11.13 (D2)
/BCD_1E2_8: J1.14, RN4.1 (R1.1)
/BCD_1E2_8_R: RN4.8 (R1.2), U11.14 (D3)
/BCD_1E3_1: J1.13, RN3.4 (R4.1)
/BCD_1E3_1_R: RN3.5 (R4.2), U11.3 (D4)
/BCD_1E3_2: J1.12, RN3.3 (R3.1)
/BCD_1E3_2_R: RN3.6 (R3.2), U11.4 (D5)
/BCD_1E3_4: J1.11, RN3.2 (R2.1)
/BCD_1E3_4_R: RN3.7 (R2.2), U11.5 (D6)
/BCD_1E3_8: J1.10, RN3.1 (R1.1)
/BCD_1E3_8_R: RN3.8 (R1.2), U11.6 (D7)
/BCD_1E4_1: J1.9, RN6.4 (R4.1)
/BCD_1E4_1_R: RN6.5 (R4.2), U12.11 (D0)
/BCD_1E4_2: J1.8, RN6.3 (R3.1)
/BCD_1E4_2_R: RN6.6 (R3.2), U12.12 (D1)
/BCD_1E4_4: J1.7, RN6.2 (R2.1)
/BCD_1E4_4_R: RN6.7 (R2.2), U12.13 (D2)
/BCD_1E4_8: J1.6, RN6.1 (R1.1)
/BCD_1E4_8_R: RN6.8 (R1.2), U12.14 (D3)
/BCD_1E5_1: J1.5, RN5.4 (R4.1)
/BCD_1E5_1_R: RN5.5 (R4.2), U12.3 (D4)
/BCD_1E5_2: J1.4, RN5.3 (R3.1)
/BCD_1E5_2_R: RN5.6 (R3.2), U12.4 (D5)
/BCD_1E5_4: J1.3, RN5.2 (R2.1)
/BCD_1E5_4_R: RN5.7 (R2.2), U12.5 (D6)
/BCD_1E5_8: J1.2, RN5.1 (R1.1)
/BCD_1E5_8_R: RN5.8 (R1.2), U12.6 (D7)
/BCD_1E6_1: J1.1, RN9.4 (R4.1)
/BCD_1E6_1_R: RN9.5 (R4.2), U14.3 (D4)
/BOOTSEL: R8.2, SW1.1
/DATA_CAN_CHANGE: J1.35, RN9.2 (R2.1)
/DATA_CAN_CHANGE_R: RN9.7 (R2.2), U14.5 (D6)
/FUNC_CMD_42: J1.42, U15.2 (QC)
/FUNC_CMD_43: J1.43, U15.3 (QD)
/FUNC_OUT_A: J1.28, RN1.3 (R3.1)
/FUNC_OUT_A_R: RN1.6 (R3.2), U10.4 (D5)
/FUNC_OUT_B: J1.29, RN1.4 (R4.1)
/FUNC_OUT_B_R: RN1.5 (R4.2), U10.3 (D4)
/INTEG_1: J1.46, U15.4 (QE)
/INTEG_2: J1.45, U15.5 (QF)
/INTEG_4: J1.44, U15.6 (QG)
/ISO_LATCH: U7.5 (VO), U10.1 (~PL), U11.1 (~PL), U12.1 (~PL), U13.1 (~PL), U14.1 (~PL), U15.12 (RCLK), U16.12 (RCLK)
/ISO_MISO_K: U9.3 (K), U10.9 (Q7)
/ISO_MOSI: U6.5 (VO), U15.14 (SER)
/ISO_OE_N: U8.5 (VO), U15.13 (~OE), U16.13 (~OE)
/ISO_SCLK: U5.5 (VO), U10.2 (CP), U11.2 (CP), U12.2 (CP), U13.2 (CP), U14.2 (CP), U15.11 (SRCLK), U16.11 (SRCLK)
/LED_ISO_PWR_A: D3.2 (A), R11.2
/LED_PWR_A: D1.2 (A), R2.2
/LED_REMOTE: R13.1, U16.5 (QF)
/LED_REMOTE_A: D4.2 (A), R13.2
/LED_STATUS: R9.1, U1.8 (GPIO5)
/LED_STATUS_A: D2.2 (A), R9.2
/LOCKOUT_N: J1.38, U15.15 (QA)
/MCU_LATCH: U1.33 (GPIO21), U7.3 (K)
/MCU_MISO: U1.32 (GPIO20), U9.5 (VO)
/MCU_MOSI: U1.35 (GPIO23), U6.3 (K)
/MCU_OE_N: U1.36 (GPIO24), U8.3 (K)
/MCU_SCLK: U1.34 (GPIO22), U5.3 (K)
/MCU_USB_DM: R6.2, U1.51 (USB_DM)
/MCU_USB_DP: R5.2, U1.52 (USB_DP)
/OVERLOAD: J1.36, RN9.3 (R3.1)
/OVERLOAD_R: RN9.6 (R3.2), U14.4 (D5)
/POL_NEG: J1.27, RN1.2 (R2.1)
/POL_NEG_R: RN1.7 (R2.2), U10.5 (D6)
/POL_POS: J1.26, RN1.1 (R1.1)
/POL_POS_R: RN1.8 (R1.2), U10.6 (D7)
/PRINT_LEVEL: J1.34, RN9.1 (R1.1)
/PRINT_LEVEL_R: RN9.8 (R1.2), U14.6 (D7)
/PRINT_PULSE: J1.33, RN2.4 (R4.1)
/PRINT_PULSE_R: RN2.5 (R4.2), U10.11 (D0)
/QSPI_SS: R8.1, U1.60 (~QSPI_SS)
/RANGE_CMD_1: J1.48, U16.15 (QA)
/RANGE_CMD_2: J1.49, U16.1 (QB)
/RANGE_CMD_4: J1.50, U16.2 (QC)
/RANGE_OUT_1: J1.32, RN2.3 (R3.1)
/RANGE_OUT_1_R: RN2.6 (R3.2), U10.12 (D1)
/RANGE_OUT_2: J1.31, RN2.2 (R2.1)
/RANGE_OUT_2_R: RN2.7 (R2.2), U10.13 (D2)
/RANGE_OUT_4: J1.30, RN2.1 (R1.1)
/RANGE_OUT_4_R: RN2.8 (R1.2), U10.14 (D3)
/RATIO_N: J1.41, U15.1 (QB)
/RUN: R7.2, SW2.1, U1.26 (RUN)
/SAMPLE_CONTACT: J1.39, Q1.3 (D)
/SAMPLE_CONTACT_DRV: Q1.1 (G), R12.1, U16.4 (QE)
/SAMPLE_PULSE: J1.40, U16.3 (QD)
/SR165_CHAIN1: U10.10 (DS), U11.9 (Q7)
/SR165_CHAIN2: U11.10 (DS), U12.9 (Q7)
/SR165_CHAIN3: U12.10 (DS), U13.9 (Q7)
/SR165_CHAIN4: U13.10 (DS), U14.9 (Q7)
/SR595_CHAIN: U15.9 (QH'), U16.14 (SER)
/SWCLK: J3.1, U1.24 (SWCLK)
/SWDIO: J3.3, U1.25 (SWDIO)
/U5_A: R14.2, U5.1 (A)
/U6_A: R15.2, U6.1 (A)
/U7_A: R16.2, U7.1 (A)
/U8_A: R17.2, U8.1 (A)
/U9_A: R18.2, U9.1 (A)
/USB_D+: J2.3 (D+), R5.1, U3.1 (I/O1), U3.6 (I/O1)
/USB_D-: J2.2 (D-), R6.1, U3.3 (I/O2), U3.4 (I/O2)
/USB_SHIELD: C1.1, J2.SH (Shield), R1.1
/VBUS_RAW: F1.1, J2.1 (VBUS)
/VREG_AVDD: C15.1, R3.2, U1.46 (VREG_AVDD)
/VREG_LX: L1.1, U1.48 (VREG_LX)
/XIN: C20.1, U1.21 (XIN), Y1.1
/XOUT: R4.1, U1.22 (XOUT)
/XOUT_R: C21.1, R4.2, Y1.3
GND: C1.2, C2.2, C3.2, C4.2, C5.2, C6.2, C7.2, C8.2, C9.2, C10.2, C11.2, C12.2, C13.2, C14.2, C15.2, C16.2, C17.2, C18.2, C19.2, C20.2, C21.2, C22.2, C37.2, D1.1 (K), D2.1 (K), J2.4 (GND), J3.2, PS1.1 (-Vin), R1.2, SW1.2, SW2.2, U1.47 (VREG_PGND), U1.61 (GND), U2.2 (GND), U3.2 (GND), U9.4 (GND), Y1.2 (G), Y1.4 (G)
ISO_+5V: C25.1, C26.1, C27.1, C28.1, C29.1, C30.1, C31.1, C32.1, C33.1, C34.1, C35.1, C36.1, R11.1, R18.1, U4.1 (OUT), U5.6 (VDD), U6.6 (VDD), U7.6 (VDD), U8.6 (VDD), U10.16 (VCC), U11.16 (VCC), U12.16 (VCC), U13.16 (VCC), U14.12 (D1), U14.14 (D3), U14.16 (VCC), U15.10 (~SRCLR), U15.16 (VCC), U16.10 (~SRCLR), U16.16 (VCC)
ISO_+9V: C23.1, C24.1, PS1.4 (+Vout), R10.1, U4.3 (IN)
ISO_GND: C23.2, C24.2, C25.2, C26.2, C27.2, C28.2, C29.2, C30.2, C31.2, C32.2, C33.2, C34.2, C35.2, C36.2, D3.1 (K), D4.1 (K), J1.37, J1.SH, PS1.3 (-Vout), Q1.2 (S), R10.2, R12.2, U4.2 (GND), U5.4 (GND), U6.4 (GND), U7.4 (GND), U8.4 (GND), U10.8 (GND), U10.15 (~CE), U11.8 (GND), U11.15 (~CE), U12.8 (GND), U12.15 (~CE), U13.8 (GND), U13.15 (~CE), U14.8 (GND), U14.10 (DS), U14.11 (D0), U14.13 (D2), U14.15 (~CE), U15.8 (GND), U16.8 (GND)

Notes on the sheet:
USB INPUT, PROTECTION, 3.3 V
NOTES
Isolated serial link (RP2354A SPI0 / PIO): SPI mode 0, MSB first, <= 1 MHz, 40 clocks per transfer. Pulse LATCH low >= 1 us, then clock 5 bytes. LATCH low: the 74HCT165s sample the meter outputs. LATCH rising edge: the 74HC595 outputs take the last two bytes clocked in. /OE (GPIO24) high = command 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
RP2354A (2 MB IN-PACKAGE FLASH)
ISOLATION: 5 x TLP2361 + B0509S
HOST SIDE (GND)
METER SIDE (ISO_GND)
METER-SIDE 5 V
COMMAND OUTPUTS: 2 x 74HC595
J1: DD-50 PLUG TO 7075 SKB
DISPLAY DATA / STATUS INPUTS: 5 x 74HCT165 (MISO = U10.Q7; chain U10 <- U11 <- U12 <- U13 <- U14)

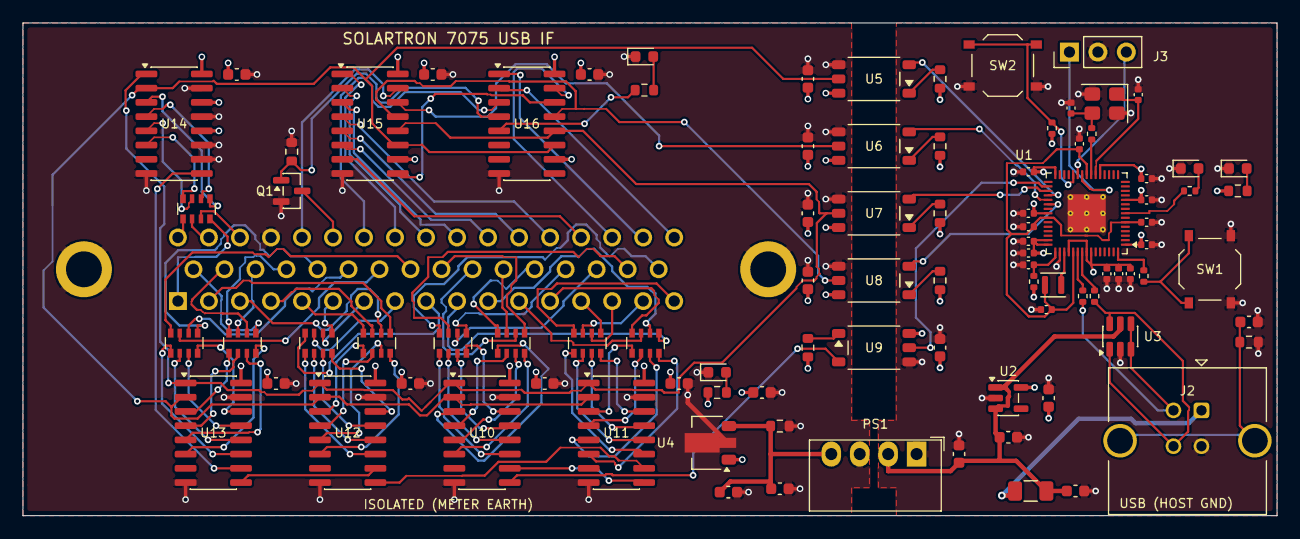
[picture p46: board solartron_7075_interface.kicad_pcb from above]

Board: 4 copper layers, 112.0 x 44.0 mm, 94 parts (1 on the bottom side), 135 nets.

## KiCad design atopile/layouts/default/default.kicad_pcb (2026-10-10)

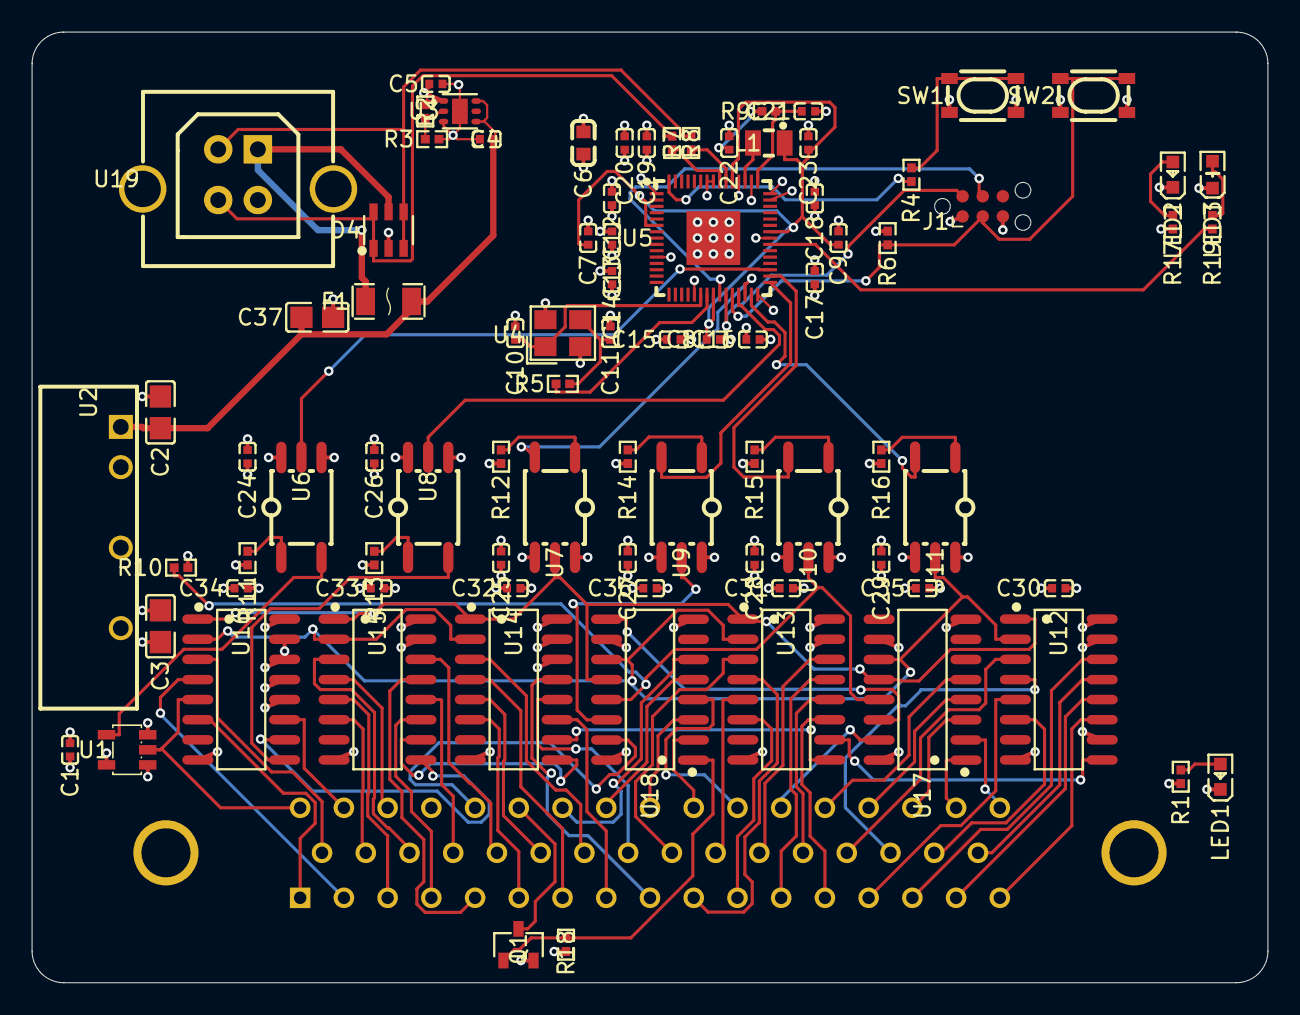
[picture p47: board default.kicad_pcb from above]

Board: 4 copper layers, 78.0 x 60.0 mm, 86 parts (1 on the bottom side), 99 nets.

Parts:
C1, C7, C8, C9, C12, C13, C14, C15, C16, C17, C18, C19, C20, C24, C25, C26, C27, C28, C29, C30, C31, C32, C33, C34, C35, C36: 100nF ±10%; C0402
C2: 4.7µF ±10%; C0805
C3, C37: 10µF ±10%; C0805
C4, C5: 1µF ±10%; C0402
C6: 10µF ±10%; C0603
C10, C11: 15pF ±5%; C0402
C21, C22, C23: 4.7µF ±20%; C0402
CN1: CONN-TH_50P-P2.76_DD50P364TXLF
D4: SOT-23-6_L2.9-W1.6-P0.95-LS2.8-BL
F1: F1206
J1: Tag-Connect_TC2030-IDC-NL_2x03_P1.27mm_Vertical
L1: IND-SMD_L2.0-W1.6_AOTA-B201610S3R3-101-T
LED1, LED2: LED0603-RD
LED3: LED0603-R-RD
Q1: SOT-23-3_L2.9-W1.3-P1.90-LS2.4-BR
R1: 3.3kΩ ±1%; R0402
R2, R18: 100kΩ ±1%; R0402
R3: 20kΩ ±1%; R0402
R4, R5: 1kΩ ±1%; R0402
R6, R10: 10kΩ ±1%; R0402
R7, R8: 27Ω ±1%; R0402
R9: 33Ω ±1%; R0402
R11, R13: 680Ω ±1%; R0402
R12, R14, R15, R16: 330Ω ±1%; R0402
R17, R19: 1.5kΩ ±1%; R0402
SW1, SW2: KEY-SMD_4P-L4.2-W3.2-P2.20-LS4.6
U1: SOT-23-5_L3.0-W1.7-P0.95-LS2.8-BR
U2: PWRM-TH_BXXXXLS-1WR3
U3: WSON-6_L2.0-W2.0-P0.65-TL-EP
U4: CRYSTAL-SMD_4P-L3.2-W2.5-BL
U5: QFN-60_L7.0-W7.0-P0.40-TL-EP3.4
U6, U7, U8, U9, U10, U11: OPTO-SMD-5_L3.7-W4.6-P1.27-LS7.0-BR
U12, U13, U14, U15, U16, U17, U18: SOIC-16_L9.9-W3.9-P1.27-LS6.0-BL
U19: USB-B-TH_921-111A1010Y10201

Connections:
+1V1: C7.1, C8.1, C9.1, C23.1, L1.2, U5.6, U5.23, U5.39, U5.50
+3V3: C5.1, C6.1, C12.1, C13.1, C14.1, C15.1, C16.1, C17.1, C18.1, C19.1, C20.1, C22.1, C24.1, C26.1, J1.1, R2.1, R6.2, R9.1, R12.1, R14.1, R15.1, R16.1, R17.1, U3.1, U5.1, U5.11, U5.20, U5.30, U5.38, U5.44, U5.45, U5.49, U5.53, U5.54, U6.6, U8.6
+5V: C2.1, C4.1, C37.1, F1.2, U2.1, U3.4, U3.6
+5V_ISO: C1.1, C3.1, C25.1, C27.1, C28.1, C29.1, C30.1, C31.1, C32.1, C33.1, C34.1, C35.1, C36.1, R1.1, R10.2, R11.1, R13.1, U1.5, U2.6, U7.6, U9.6, U10.6, U11.6, U12.16, U13.16, U14.14, U14.16, U15.16, U16.13, U16.16, U17.10, U17.16, U18.10, U18.16
AN: R11.2, U6.1
BOOTSEL_SW: R4.2, SW1.1, SW1.2
CLK: J1.4, U5.24
DATA_N: D4.3, D4.4, R8.1, U19.2
DATA_P: D4.1, D4.6, R7.1, U19.3
DIO: J1.2, U5.25
DRDY: U5.33, U6.5
DRDY_ISO: U1.4, U6.3
GND: C2.2, C4.2, C5.2, C6.2, C7.2, C8.2, C9.2, C10.2, C11.2, C12.2, C13.2, C14.2, C15.2, C16.2, C17.2, C18.2, C19.2, C20.2, C21.2, C22.2, C23.2, C24.2, C26.2, C37.2, D4.2, J1.5, LED2.1, LED3.2, R3.2, SW1.3, SW1.4, SW2.3, SW2.4, U2.2, U3.3, U3.7, U4.2, U4.4, U5.47, U5.61, U6.4, U8.4, U19.4, U19.5, U19.6
GND_ISO: C1.2, C3.2, C25.2, C27.2, C28.2, C29.2, C30.2, C31.2, C32.2, C33.2, C34.2, C35.2, C36.2, CN1.37, CN1.S1, CN1.S2, LED1.1, Q1.2, R18.2, U1.1, U1.3, U2.4, U7.4, U9.4, U10.4, U11.4, U12.8, U12.10, U12.15, U13.8, U13.15, U14.8, U14.15, U15.8, U15.15, U16.8, U16.12, U16.14, U16.15, U17.8, U18.8
LATCH: U5.28, U7.3
LATCH_ISO: U7.5, U12.1, U13.1, U14.1, U15.1, U16.1, U17.12, U18.12
LDO_FB: R2.2, R3.1, U3.2
LED_ISO_A: LED1.2, R1.2
LED_PWR_A: LED2.2, R17.2
LED_STATUS_A: LED3.1, R19.2
MISO: U5.27, U8.5
MISO_ISO: U8.3, U16.9
MOSI: U5.31, U9.3
MOSI_ISO: U9.5, U18.14
N_RESET: J1.3, R6.1, SW2.1, SW2.2, U5.26
OE_N: U5.32, U10.3
OE_N_ISO: R10.1, U10.5, U17.13, U18.13
QSPI_SS: R4.1, U5.60
SAMPLE_CONTACT_GATE: Q1.1, R18.1, U18.1
SCK: U5.29, U11.3
SCK_ISO: U11.5, U12.2, U13.2, U14.2, U15.2, U16.2, U17.11, U18.11
SI_CHAIN_1: U15.9, U16.10
SI_CHAIN_2: U14.9, U15.10
SI_CHAIN_3: U13.9, U14.10
SI_CHAIN_4: U12.9, U13.10
SKB01_D6_1: CN1.1, U16.6
SKB02_D5_8: CN1.2, U16.4
SKB03_D5_4: CN1.3, U15.5
SKB04_D5_2: CN1.4, U15.11
SKB05_D5_1: CN1.5, U15.13
SKB06_D4_8: CN1.6, U14.6
SKB07_D4_4: CN1.7, U14.4
SKB08_D4_2: CN1.8, U14.11
SKB09_D4_1: CN1.9, U14.13
SKB10_D3_8: CN1.10, U13.4
SKB11_D3_4: CN1.11, U13.6
SKB12_D3_2: CN1.12, U13.13
SKB13_D3_1: CN1.13, U13.11
SKB14_D2_8: CN1.14, U12.5
SKB15_D2_4: CN1.15, U12.14
SKB16_D2_2: CN1.16, U12.12
SKB17_D2_1: CN1.17, U12.11
SKB18_D1_8: CN1.18, U16.3
SKB19_D1_4: CN1.19, U15.6
SKB20_D1_2: CN1.20, U15.3
SKB21_D1_1: CN1.21, U15.12
SKB22_D0_8: CN1.22, U15.14
SKB23_D0_4: CN1.23, U14.5
SKB24_D0_2: CN1.24, U14.3
SKB25_D0_1: CN1.25, U14.12
SKB26_POL_POS: CN1.26, U13.3
SKB27_POL_NEG: CN1.27, U13.5
SKB28_FUNC_OUT_A: CN1.28, U13.14
SKB29_FUNC_OUT_B: CN1.29, U13.12
SKB30_RANGE_OUT_4: CN1.30, U12.3
SKB31_RANGE_OUT_2: CN1.31, U12.4
SKB32_RANGE_OUT_1: CN1.32, U12.6
SKB33_PRINT_PULSE: CN1.33, U12.13
SKB34_PRINT_LEVEL: CN1.34, U1.2, U16.5
SKB35_DATA_CAN_CHANGE: CN1.35, U16.11
SKB36_OVERLOAD: CN1.36, U15.4
SKB38_LOCKOUT: CN1.38, U18.15
SKB39_SAMPLE_CONTACT: CN1.39, Q1.3
SKB40_SAMPLE_PULSE: CN1.40, U18.6
SKB41_RATIO: CN1.41, U18.5
SKB42_FUNC_CMD_A: CN1.42, U18.3
SKB43_FUNC_CMD_B: CN1.43, U18.2
SKB44_INT_TIME_4: CN1.44, U18.4
SKB45_INT_TIME_2: CN1.45, U17.15
SKB46_INT_TIME_1: CN1.46, U17.5
SKB47_AUTORANGE: CN1.47, U17.4
SKB48_RANGE_CMD_1: CN1.48, U17.3
SKB49_RANGE_CMD_2: CN1.49, U17.1
SKB50_RANGE_CMD_4: CN1.50, U17.2
SO_CHAIN_1: U17.14, U18.9
STATUS_LED: R19.1, U5.37
USB_DM: R8.2, U5.51
USB_DP: R7.2, U5.52
VBUS: D4.5, F1.1, U19.1
VREG_AVDD: C21.1, R9.2, U5.46
VREG_LX: L1.1, U5.48
XIN: C10.1, U4.1, U5.21
XOUT: R5.1, U5.22
XTAL_OUT: C11.1, R5.2, U4.3
opto_latch-AN: R12.2, U7.1
opto_miso-AN: R13.2, U8.1
opto_mosi-AN: R14.2, U9.1
opto_oe_n-AN: R15.2, U10.1
opto_sck-AN: R16.2, U11.1

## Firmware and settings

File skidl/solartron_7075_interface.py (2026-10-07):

#!/usr/bin/env python3
"""
Solartron 7075 DVM -> USB interface, described with SKiDL.

The 7075's Parallel BCD Interface Unit (70754, manual section 9) presents a
50-way Cannon D socket (SKB) carrying TTL-level BCD display data, status
outputs and remote-control command inputs. This board plugs straight into
that socket, captures the 36 meter outputs with 74HCT165 shift registers,
drives the 13 command inputs from 74HC595 shift registers, and talks to an
RP2354A over just five optocoupled lines (SCLK, MOSI, LATCH, /OE -> meter
side; MISO <- meter side). The meter side is powered from USB through an
isolated DC/DC converter, so the USB host's ground never touches the meter.

Run:  python3 solartron_7075_interface.py   (or ./build.sh for the whole flow)
Outputs go to ./output: KiCad netlist, ERC log and the unplaced .kicad_pcb
that scripts/layout_pcb.py and scripts/route_pcb.py turn into the board.
"""

import os
import pathlib

HERE = pathlib.Path(__file__).resolve().parent
OUT = HERE / "output"
OUT.mkdir(exist_ok=True)

# Point SKiDL at the KiCad 10 libraries before importing it.
os.environ.setdefault("KICAD10_SYMBOL_DIR", "/usr/share/kicad/symbols")
os.environ.setdefault("KICAD10_FOOTPRINT_DIR", "/usr/share/kicad/footprints")
os.environ.setdefault("KICAD_SYMBOL_DIR", os.environ["KICAD10_SYMBOL_DIR"])

from skidl import (  # noqa: E402
    KICAD10,
    POWER,
    TEMPLATE,
    Net,
    Part,
    ERC,
    generate_netlist,
    generate_pcb,
    generate_schematic,
    lib_search_paths,
    set_default_tool,
    subcircuit,
)

import builtins  # noqa: E402

NC = builtins.NC  # SKiDL keeps its no-connect net and default circuit in builtins
set_default_tool(KICAD10)
lib_search_paths[KICAD10].append(str(HERE / "lib"))

LOCAL_LIB = "Solartron7075"

# ---------------------------------------------------------------------------
# Footprints and part helpers
# ---------------------------------------------------------------------------
FP_R = "Resistor_SMD:R_0603_1608Metric"
FP_C = "Capacitor_SMD:C_0603_1608Metric"
FP_LED = "LED_SMD:LED_0603_1608Metric"
FP_RN = "Resistor_SMD:R_Array_Convex_4x0603"
FP_SO16 = "Package_SO:SOIC-16_3.9x9.9mm_P1.27mm"
FP_OPTO = "Package_SO:Toshiba_SOIC-5-6_4.4x3.6mm_P1.27mm"


def tag(part, lcsc, mpn, mfr):
    """Attach sourcing fields (exported to the netlist / BOM)."""
    part.fields["LCSC"] = lcsc
    part.fields["MPN"] = mpn
    part.fields["Manufacturer"] = mfr
    return part


# Basic-library passives (JLCPCB "basic" parts where available).
# 0603 by default; 0402 for the parts packed around the RP2354A.
R_LCSC = {
    "0603": {
        "27": ("C25190", "0603WAF270JT5E"),
        "390": ("C23151", "0603WAF3900T5E"),
        "820": ("C23253", "0603WAF8200T5E"),
        "1k": ("C21190", "0603WAF1001T5E"),
        "2.2k": ("C4190", "0603WAF2201T5E"),
        "10k": ("C25804", "0603WAF1002T5E"),
        "100k": ("C25803", "0603WAF1003T5E"),
        "1M": ("C22935", "0603WAF1004T5E"),
    },
    "0402": {
        "27": ("C25100", "0402WGF270JTCE"),
        "33": ("C25105", "0402WGF330JTCE"),
        "1k": ("C11702", "0402WGF1001TCE"),
        "10k": ("C25744", "0402WGF1002TCE"),
    },
}
C_LCSC = {
    "0603": {
        "4.7n": ("C53987", "0603B472K500NT", "FH"),
        "100n": ("C14663", "CC0603KRX7R9BB104", "YAGEO"),
        "1u": ("C15849", "CL10A105KB8NNNC", "Samsung"),
        "2.2u": ("C23630", "CL10A225KO8NNNC", "Samsung"),
        "4.7u": ("C19666", "CL10A475KO8NNNC", "Samsung"),
        "10u": ("C19702", "CL10A106KP8NNNC", "Samsung"),
    },
    "0402": {
        "15p": ("C1548", "0402CG150J500NT", "FH"),
        "100n": ("C1525", "CL05B104KO5NNNC", "Samsung"),
        "1u": ("C52923", "CL05A105KA5NQNC", "Samsung"),
        "4.7u": ("C23733", "CL05A475MP5NRNC", "Samsung"),
    },
}
FP_SIZE = {"0603": "1608Metric", "0402": "1005Metric"}

r_tmpl = Part("Device", "R", dest=TEMPLATE, footprint=FP_R)
c_tmpl = Part("Device", "C", dest=TEMPLATE, footprint=FP_C)
led_tmpl = Part("Device", "LED", dest=TEMPLATE, footprint=FP_LED)
rn_tmpl = Part("Device", "R_Pack04", dest=TEMPLATE, footprint=FP_RN)


def R(value, size="0603"):
    r = r_tmpl(value=value, footprint=f"Resistor_SMD:R_{size}_{FP_SIZE[size]}")
    lcsc, mpn = R_LCSC[size][value]
    return tag(r, lcsc, mpn, "UNI-ROYAL")


def C(value, size="0603"):
    c = c_tmpl(value=value, footprint=f"Capacitor_SMD:C_{size}_{FP_SIZE[size]}")
    lcsc, mpn, mfr = C_LCSC[size][value]
    return tag(c, lcsc, mpn, mfr)


def decouple(pos, neg, value="100n", size="0603"):
    c = C(value, size)
    c[1] += pos
    c[2] += neg
    return c


def LED(colour):
    led = led_tmpl(value=colour)
    if colour == "green":  # AlInGaP yellow-green, ~2.0 V: bright enough from 3.3 V
        return tag(led, "C125094", "LTST-C190KGKT", "Lite-On")
    return tag(led, "C2286", "KT-0603R", "Hubei KENTO")


# ---------------------------------------------------------------------------
# Global nets
# ---------------------------------------------------------------------------
def power_net(name):
    n = Net(name)
    n.drive = POWER
    return n


# USB / host side
vbus_raw = Net("VBUS_RAW")
vbus = power_net("+5V_USB")
v3v3 = power_net("+3V3")
gnd = power_net("GND")

# Isolated / meter side
iso_9v = power_net("ISO_+9V")
iso_5v = power_net("ISO_+5V")
iso_gnd = power_net("ISO_GND")  # = Solartron pin 37 "EARTH / Logic 0"

# MCU <-> optocoupler (host side)
mcu_sclk, mcu_mosi, mcu_miso, mcu_latch, mcu_oe_n = (
    Net("MCU_SCLK"), Net("MCU_MOSI"), Net("MCU_MISO"), Net("MCU_LATCH"), Net("MCU_OE_N"))

# Optocoupler -> shift registers (meter side)
iso_sclk, iso_mosi, iso_latch, iso_oe_n = (
    Net("ISO_SCLK"), Net("ISO_MOSI"), Net("ISO_LATCH"), Net("ISO_OE_N"))

# ---------------------------------------------------------------------------
# Solartron 7075 / 70754 SKB pin map (manual section 9, connection table).
# ---------------------------------------------------------------------------
# Outputs from the meter (TTL, '1' = +2.4..+6 V from 6 kOhm, '0' sinks 10 mA)
BCD_PINS = {}  # (decade, weight) -> pin
BCD_PINS[(6, 1)] = 1  # the "half" digit: 1 x 10^6
for decade, first_pin in zip((5, 4, 3, 2, 1, 0), (2, 6, 10, 14, 18, 22)):
    for i, weight in enumerate((8, 4, 2, 1)):
        BCD_PINS[(decade, weight)] = first_pin + i

METER_OUT = {f"BCD_1E{d}_{w}": p for (d, w), p in BCD_PINS.items()}
METER_OUT.update({
    "POL_POS": 26,        # +ve polarity
    "POL_NEG": 27,        # -ve polarity (both 0 = AC / ohms)
    "FUNC_OUT_A": 28,     # function output code (28,29): 11 DC, 01 AC, 10 ohm, 00 check
    "FUNC_OUT_B": 29,
    "RANGE_OUT_4": 30,    # range output code
    "RANGE_OUT_2": 31,
    "RANGE_OUT_1": 32,
    "PRINT_PULSE": 33,    # 10-30 us high at end of measurement
    "PRINT_LEVEL": 34,    # high when the output data is valid
    "DATA_CAN_CHANGE": 35,
    "OVERLOAD": 36,
})
METER_GND_PIN = 37
# Inputs to the meter (TTL, '1' = +2.4..+5 V, '0' must sink 5 mA)
METER_IN = {
    "LOCKOUT_N": 38,      # 0 = front panel lockout (forces REMOTE)
    "SAMPLE_CONTACT": 39,  # contact closure to pin 37 starts a reading
    "SAMPLE_PULSE": 40,   # +3..+8 V pulse > 100 us starts a reading
    "RATIO_N": 41,        # 0 = ratio
    "FUNC_CMD_42": 42,    # function command (43,42): 11 DC, 01 AC, 10 ohm, 00 check
    "FUNC_CMD_43": 43,
    "INTEG_4": 44,        # integration time code (4,2,1)
    "INTEG_2": 45,
    "INTEG_1": 46,
    "AUTORANGE_INH": 47,  # 1 = commanded range, 0 = autorange
    "RANGE_CMD_1": 48,    # range command code (4,2,1 on 50,49,48)
    "RANGE_CMD_2": 49,
    "RANGE_CMD_4": 50,
}

meter = {name: Net(name) for name in list(METER_OUT) + list(METER_IN)}


# ---------------------------------------------------------------------------
# Sub-circuits
# ---------------------------------------------------------------------------
@subcircuit
def usb_input():
    """Vertical USB-B, polyfuse, ESD clamp, 3.3 V LDO."""
    j = Part("Connector", "USB_B", ref="J2", footprint="Connector_USB:USB_B_TE_5787834_Vertical")
    tag(j, "C592900", "5787834-1", "TE Connectivity")
    usb_dp, usb_dm = Net("USB_D+"), Net("USB_D-")
    shield = Net("USB_SHIELD")
    j["VBUS"] += vbus_raw
    j["D+"] += usb_dp
    j["D-"] += usb_dm
    j["GND"] += gnd
    j["Shield"] += shield

    # Shield to ground through 1M || 4.7 nF (keeps chassis/shield currents out of GND)
    r_sh, c_sh = R("1M"), C("4.7n")
    r_sh[1, 2] += shield, gnd
    c_sh[1, 2] += shield, gnd

    f = Part("Device", "Polyfuse", ref="F1", value="500mA", footprint="Fuse:Fuse_1206_3216Metric")
    tag(f, "C20799", "SMD1206P050TF", "RUILON")
    f[1, 2] += vbus_raw, vbus

    esd = Part("Power_Protection", "USBLC6-2SC6", ref="U3", footprint="Package_TO_SOT_SMD:SOT-23-6")
    tag(esd, "C7519", "USBLC6-2SC6", "STMicroelectronics")
    esd[1] += usb_dp
    esd[6] += usb_dp
    esd[3] += usb_dm
    esd[4] += usb_dm
    esd["VBUS"] += vbus
    esd["GND"] += gnd

    decouple(vbus, gnd, "10u")

    ldo = Part("Regulator_Linear", "AP2112K-3.3", ref="U2", footprint="Package_TO_SOT_SMD:SOT-23-5")
    tag(ldo, "C51118", "AP2112K-3.3TRG1", "Diodes Incorporated")
    ldo["VIN"] += vbus
    ldo["EN"] += vbus
    ldo["GND"] += gnd
    ldo["VOUT"] += v3v3
    ldo["NC"] += NC
    decouple(vbus, gnd, "1u")
    decouple(v3v3, gnd, "10u")

    # Host-side power LED
    led, r = LED("green"), R("1k")
    v3v3 & r & Net("LED_PWR_A") & led["A,K"] & gnd
    return usb_dp, usb_dm


@subcircuit
def mcu(usb_dp, usb_dm):
    """RP2354A (2 MB in-package flash) with crystal, core SMPS, USB, SWD, buttons."""
    u = Part("MCU_RaspberryPi", "RP2354A", ref="U1",
             footprint="Package_DFN_QFN:QFN-60-1EP_7x7mm_P0.4mm_EP3.4x3.4mm_ThermalVias")
    tag(u, "C41378174", "RP2354A", "Raspberry Pi")

    dvdd = power_net("+1V1_DVDD")
    vreg_avdd = power_net("VREG_AVDD")  # 3V3 through a 33R / 4.7 uF filter

    # 3.3 V rails, one 100 nF per pin
    for p in u["IOVDD"]:
        p += v3v3
        decouple(v3v3, gnd, size="0402")
    for name in ("USB_OTP_VDD", "ADC_AVDD", "QSPI_IOVDD"):
        u[name] += v3v3
        decouple(v3v3, gnd, size="0402")
    u["GND"] += gnd

    # On-chip switching regulator: VREG_VIN -> VREG_LX -> 3.3 uH -> DVDD (1.1 V)
    u["VREG_VIN"] += v3v3
    decouple(v3v3, gnd, "4.7u", "0402")
    r_av = R("33", "0402")
    r_av[1, 2] += v3v3, vreg_avdd
    u["VREG_AVDD"] += vreg_avdd
    decouple(vreg_avdd, gnd, "4.7u", "0402")
    u["VREG_PGND"] += gnd
    l1 = Part("Device", "L", ref="L1", value="3.3uH", footprint="Inductor_SMD:L_Murata_DFE201610P")
    tag(l1, "C42411119", "AOTA-B201610S3R3-101-T", "Abracon")
    vreg_lx = Net("VREG_LX")
    u["VREG_LX"] += vreg_lx
    l1[1, 2] += vreg_lx, dvdd
    u["VREG_FB"] += dvdd
    decouple(dvdd, gnd, "4.7u", "0402")
    for p in u["DVDD"]:
        p += dvdd
        decouple(dvdd, gnd, size="0402")

    # 12 MHz crystal (RP2350 hardware design guide values: 15 pF loads, 1k series)
    y = Part("Device", "Crystal_GND24", ref="Y1", value="12MHz",
             footprint="Crystal:Crystal_SMD_3225-4Pin_3.2x2.5mm")
    tag(y, "C20625731", "ABM8-272-T3", "Abracon")
    xin, xout, xout_r = Net("XIN"), Net("XOUT"), Net("XOUT_R")
    u["XIN"] += xin
    u["XOUT"] += xout
    r_x = R("1k", "0402")
    r_x[1, 2] += xout, xout_r
    y[1] += xin
    y[3] += xout_r
    y[2] += gnd
    y[4] += gnd
    for n in (xin, xout_r):
        c = C("15p", "0402")
        c[1, 2] += n, gnd

    # USB with 27R series resistors (RP2350 has the D+ pull-up on chip)
    for pin, net in (("USB_DP", usb_dp), ("USB_DM", usb_dm)):
        r = R("27", "0402")
        mcu_side = Net(f"MCU_{pin}")
        r[1, 2] += net, mcu_side
        u[pin] += mcu_side

    # RUN (reset) with pull-up and button; BOOTSEL on QSPI_SS
    run = Net("RUN")
    u["RUN"] += run
    r_run = R("10k", "0402")
    r_run[1, 2] += v3v3, run
    sw_run = Part("Switch", "SW_Push", ref="SW2", value="RESET",
                  footprint="Button_Switch_SMD:SW_Push_1P1T_XKB_TS-1187A")
    tag(sw_run, "C318884", "TS-1187A-B-A-B", "XKB Connection")
    sw_run[1, 2] += run, gnd

    qspi_ss, boot = Net("QSPI_SS"), Net("BOOTSEL")
    u[60] += qspi_ss  # ~QSPI_SS
    r_boot = R("1k", "0402")
    r_boot[1, 2] += qspi_ss, boot
    sw_boot = Part("Switch", "SW_Push", ref="SW1", value="BOOTSEL",
                   footprint="Button_Switch_SMD:SW_Push_1P1T_XKB_TS-1187A")
    tag(sw_boot, "C318884", "TS-1187A-B-A-B", "XKB Connection")
    sw_boot[1, 2] += boot, gnd
    # Flash is inside the RP2354A package: the QSPI data/clock pins stay unconnected.
    for name in ("QSPI_SD0", "QSPI_SD1", "QSPI_SD2", "QSPI_SD3", "QSPI_SCLK"):
        u[name] += NC

    # SWD debug header (Raspberry Pi 3-pin debug order: SWCLK, GND, SWDIO)
    swd = Part("Connector_Generic", "Conn_01x03", ref="J3", value="SWD",
               footprint="Connector_PinHeader_2.54mm:PinHeader_1x03_P2.54mm_Vertical")
    tag(swd, "C2937625", "PZ254V-11-03P", "XFCN")
    swclk, swdio = Net("SWCLK"), Net("SWDIO")
    u["SWCLK"] += swclk
    u["SWDIO"] += swdio
    swd[1, 2, 3] += swclk, gnd, swdio

    # Isolated link on GPIO20-24 (one contiguous run of pins facing the
    # optocouplers): GPIO20/22/23 = SPI0 RX/SCK/TX, GPIO21 = LATCH, GPIO24 = /OE.
    # PIO can drive the same pins if hardware SPI timing is not wanted.
    u["GPIO20"] += mcu_miso
    u["GPIO21"] += mcu_latch
    u["GPIO22"] += mcu_sclk
    u["GPIO23"] += mcu_mosi
    u["GPIO24"] += mcu_oe_n

    # Status LED on GPIO5 (active high)
    led_net = Net("LED_STATUS")
    u["GPIO5"] += led_net
    led, r = LED("green"), R("1k", "0402")
    led_net & r & Net("LED_STATUS_A") & led["A,K"] & gnd

    used = {5, 20, 21, 22, 23, 24}
    for p in u.pins:
        if p.name.startswith("GPIO") and int(p.name[4:].split("/")[0]) not in used:
            p += NC


@subcircuit
def opto(ref, led_supply, led_r, led_drive, out_vdd, out_gnd, out_net):
    """TLP2361 15 MBd logic optocoupler (inverting, totem-pole output).

    The LED anode goes to its supply through led_r and the cathode is pulled
    low by the driving logic, so the overall path is non-inverting and an
    undriven input (MCU in reset) gives a HIGH output.
    """
    # KiCad has no TLP2361 symbol; the TLP2310 symbol has the identical SO6
    # (5-lead) pinout: 1 A, 3 K, 4 GND, 5 VO, 6 VCC.
    u = Part("Isolator", "TLP2310", ref=ref, value="TLP2361", footprint=FP_OPTO)
    tag(u, "C107626", "TLP2361(TPL,E", "Toshiba")
    anode = Net(f"{ref}_A")
    r = R(led_r)
    r[1, 2] += led_supply, anode
    u["A"] += anode
    u["K"] += led_drive
    u["VDD"] += out_vdd
    u["GND"] += out_gnd
    u["VO"] += out_net
    decouple(out_vdd, out_gnd)


@subcircuit
def isolated_power():
    """USB 5 V -> isolated 9 V (B0509S) -> 78L05 -> ISO_+5V for the meter side."""
    ps = Part("Converter_DCDC_Isolated", "MEE1S0509SC", ref="PS1", value="B0509S-1WR3",
              footprint="Converter_DCDC:Converter_DCDC_Murata_MEE1SxxxxSC_THT")
    tag(ps, "C7500906", "B0509S-1WR3", "EVISUN")
    ps["+Vin"] += vbus
    ps["-Vin"] += gnd
    ps["+Vout"] += iso_9v
    ps["-Vout"] += iso_gnd
    decouple(vbus, gnd, "4.7u")      # module datasheet: Cin 4.7 uF
    decouple(iso_9v, iso_gnd, "2.2u")  # module datasheet: Cout 2.2 uF (9 V)
    # Bleed resistor so the unregulated module sees roughly its 10 % minimum load
    r_min = R("2.2k")
    r_min[1, 2] += iso_9v, iso_gnd

    reg = Part("Regulator_Linear", "L78L05_SOT89", ref="U4", value="78L05",
               footprint="Package_TO_SOT_SMD:SOT-89-3")
    tag(reg, "C347258", "78L05 (SOT-89)", "UMW")
    reg["IN"] += iso_9v
    reg["GND"] += iso_gnd
    reg["OUT"] += iso_5v
    decouple(iso_9v, iso_gnd, "1u")
    decouple(iso_5v, iso_gnd, "10u")

    led, r = LED("green"), R("1k")
    iso_5v & r & Net("LED_ISO_PWR_A") & led["A,K"] & iso_gnd


@subcircuit
def input_shift_registers():
    """5 x 74HCT165 capturing the 36 meter outputs (plus 4 fixed check bits).

    Each register serves a group of physically adjacent connector pins (keeps
    the routing around the DD-50 short). Bit order on MISO after a LATCH pulse,
    MSB of each byte first (byte0 = U10, whose Q7 drives the MISO opto):
      byte0 U10: POL_POS POL_NEG FUNC_OUT_A FUNC_OUT_B RANGE_OUT_4 RANGE_OUT_2 RANGE_OUT_1 PRINT_PULSE
      byte1 U11: 10^3 digit (8 4 2 1), 10^2 digit (8 4 2 1)
      byte2 U12: 10^5 digit, 10^4 digit
      byte3 U13: 10^1 digit, 10^0 digit
      byte4 U14: PRINT_LEVEL DATA_CAN_CHANGE OVERLOAD BCD_1E6_1  1 0 1 0 (fixed check pattern)
    """
    one, zero = iso_5v, iso_gnd

    def digits(hi, lo):
        return [f"BCD_1E{hi}_{w}" for w in (8, 4, 2, 1)] + [f"BCD_1E{lo}_{w}" for w in (8, 4, 2, 1)]

    bytes_ = [
        ["POL_POS", "POL_NEG", "FUNC_OUT_A", "FUNC_OUT_B",
         "RANGE_OUT_4", "RANGE_OUT_2", "RANGE_OUT_1", "PRINT_PULSE"],
        digits(3, 2),
        digits(5, 4),
        digits(1, 0),
        ["PRINT_LEVEL", "DATA_CAN_CHANGE", "OVERLOAD", "BCD_1E6_1", one, zero, one, zero],
    ]

    # Series resistors (4-element arrays) between the connector and the 165 inputs:
    # ESD current limiting and limits back-feeding when only one side is powered.
    signals = [s for b in bytes_ for s in b if isinstance(s, str)]
    filtered = {}
    for i in range(0, len(signals), 4):
        rn = rn_tmpl(value="10k")
        tag(rn, "C29718", "4D03WGJ0103T5E", "UNI-ROYAL")
        for k, sig in enumerate(signals[i:i + 4]):
            filtered[sig] = Net(f"{sig}_R")
            rn[k + 1] += meter[sig]          # Rn.1
            rn[8 - k] += filtered[sig]       # Rn.2

    q7_prev = iso_miso_drive = Net("ISO_MISO_K")  # first register's Q7 sinks the MISO opto LED
    for idx, bits in enumerate(bytes_):
        u = Part("74xx", "74HC165", ref=f"U{10 + idx}", value="74HCT165", footprint=FP_SO16)
        tag(u, "C456131", "74HCT165D,653", "Nexperia")
        u["VCC"] += iso_5v
        u["GND"] += iso_gnd
        decouple(iso_5v, iso_gnd)
        u[1] += iso_latch  # ~PL
        u["CP"] += iso_sclk
        u[15] += iso_gnd  # ~CE
        u[7] += NC  # ~Q7
        u[9] += q7_prev  # Q7
        for k, sig in enumerate(bits):  # bits[0] -> D7 (shifted out first)
            u[f"D{7 - k}"] += filtered[sig] if isinstance(sig, str) else sig
        if idx == len(bytes_) - 1:
            u["DS"] += iso_gnd
        else:
            q7_prev = Net(f"SR165_CHAIN{idx + 1}")
            u["DS"] += q7_prev
    return iso_miso_drive


@subcircuit
def output_shift_registers():
    """2 x 74HC595 driving the 13 meter command inputs.

    Outputs are high-impedance until the MCU pulls /OE low; the meter's TTL
    inputs then float to '1', which is the meter's "nothing commanded" state.
    The last two bytes clocked in (of the 5 per transfer) land here:
      byte4 -> U15: QH..QA = AUTORANGE_INH INTEG_4 INTEG_2 INTEG_1 FUNC_CMD_43 FUNC_CMD_42 RATIO_N LOCKOUT_N
      byte3 -> U16: QH..QA = - - LED_REMOTE SAMPLE_CONTACT SAMPLE_PULSE RANGE_CMD_4 RANGE_CMD_2 RANGE_CMD_1
    """
    u15 = Part("74xx", "74HC595", ref="U15", footprint=FP_SO16)
    u16 = Part("74xx", "74HC595", ref="U16", footprint=FP_SO16)
    chain = Net("SR595_CHAIN")
    for u in (u15, u16):
        tag(u, "C5947", "74HC595D,118", "Nexperia")
        u["VCC"] += iso_5v
        u["GND"] += iso_gnd
        decouple(iso_5v, iso_gnd)
        u["SRCLK"] += iso_sclk
        u["RCLK"] += iso_latch
        u[13] += iso_oe_n  # ~OE
        u[10] += iso_5v  # ~SRCLR
    u15["SER"] += iso_mosi
    u15[9] += chain  # QH' (pin names with ' are mangled by SKiDL, so use the number)
    u16["SER"] += chain
    u16[9] += NC  # QH'

    u15["QA"] += meter["LOCKOUT_N"]
    u15["QB"] += meter["RATIO_N"]
    u15["QC"] += meter["FUNC_CMD_42"]
    u15["QD"] += meter["FUNC_CMD_43"]
    u15["QE"] += meter["INTEG_1"]
    u15["QF"] += meter["INTEG_2"]
    u15["QG"] += meter["INTEG_4"]
    u15["QH"] += meter["AUTORANGE_INH"]

    u16["QA"] += meter["RANGE_CMD_1"]
    u16["QB"] += meter["RANGE_CMD_2"]
    u16["QC"] += meter["RANGE_CMD_4"]
    u16["QD"] += meter["SAMPLE_PULSE"]

    # CONTACT SAMPLE needs a real closure to pin 37: small N-MOSFET, gate held
    # low by 100k while the 595 outputs are disabled.
    gate = Net("SAMPLE_CONTACT_DRV")
    u16["QE"] += gate
    q = Part("Transistor_FET", "2N7002", ref="Q1", footprint="Package_TO_SOT_SMD:SOT-23")
    tag(q, "C8545", "2N7002", "CJ")
    q["G"] += gate
    q["D"] += meter["SAMPLE_CONTACT"]
    q["S"] += iso_gnd
    r_g = R("100k")
    r_g[1, 2] += gate, iso_gnd

    # "Remote active" indicator on the meter side
    led_net = Net("LED_REMOTE")
    u16["QF"] += led_net
    led, r = LED("red"), R("1k")
    led_net & r & Net("LED_REMOTE_A") & led["A,K"] & iso_gnd
    u16["QG"] += NC
    u16["QH"] += NC


@subcircuit
def meter_connector():
    """DD-50 male, vertical, mounted on the underside so it plugs into SKB."""
    j = Part(LOCAL_LIB, "DD50_Pins_MountingHoles", ref="J1", value="DD-50 plug")
    tag(j, "C17502305", "D50P24A4PA00LF", "Amphenol ICC")
    for name, pin in list(METER_OUT.items()) + list(METER_IN.items()):
        j[pin] += meter[name]
    j[METER_GND_PIN] += iso_gnd
    j["SH"] += iso_gnd  # shell / jackscrew holes: meter earth
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

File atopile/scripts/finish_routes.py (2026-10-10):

#!/usr/bin/env python3
"""
Route the connections Freerouting left open, with a small grid router.

First, signal-net vias and track ends that lead nowhere (Freerouting
leaves some where it gave up on a connection) are removed. Then, for every
net whose copper is still in more than one piece (KiCad's connectivity,
with the zones filled in memory), the two closest pieces are joined by an
A* search on a 0.05 mm grid over F.Cu and B.Cu, with through
vias. Clearances follow the net classes plus a margin for the grid:
  * track centre: width/2 + clearance from other nets' copper, the board
    edge and the isolation keep-out strip
  * via: 0.6 mm pad + clearance on both outer layers, 0.25 mm hole to hole,
    never inside an SMD pad
The search runs in a window around the gap (widened if it fails), so it
only touches the area of the open connection. If some connections fail,
they are tried again first, before the others, and the better result is
kept. A connection that still fails is routed ignoring other signal nets'
tracks; the track segments and vias that path collides with are ripped up
and their nets reconnected in the next round (up to MAX_ROUNDS). Pads, the
plane via drops and the pre-routed LDO block never move.

    python3 scripts/finish_routes.py           # report what it would add
    python3 scripts/finish_routes.py --write   # clean up and add the tracks and vias

Run after scripts/import_routing.py, then check with KiCad's DRC
(scripts/export_pcb.py does that).

Needs KiCad's pcbnew Python module (KiCad 9/10) and numpy; writes through
atopile's Python (see scripts/import_routing.py).
"""

import argparse
import heapq
import math
import sys
from pathlib import Path

import numpy as np

sys.path.insert(0, str(Path(__file__).resolve().parent))
import import_routing  # noqa: E402

LAYOUT = import_routing.LAYOUT
RES = 0.05  # grid pitch, mm
GRID_MARGIN = 0.04  # covers diagonal steps between grid points
CLEARANCE = {"Default": 0.15, "Power": 0.2}
WIDTH = {"Default": 0.2, "Power": 0.4}
POWER_NETS = ("VBUS", "+5V")
VIA_D, VIA_DRILL, HOLE_GAP = 0.6, 0.3, 0.25
EDGE = 0.3  # copper to board edge
BOARD_W, BOARD_H = 78.0, 60.0
BARRIER_KEEPOUT = 1.6
VIA_COST = 1.5  # mm of track a via is worth
BEND_COST = 0.3  # mm per 45 degrees of turn
WINDOWS = (3.0, 6.0, 12.0)  # search margins around the gap, mm
MAX_ROUNDS = 12
RIP_COST = 20.0  # cost per mm of crossing another net's track when ripping up
RIP_HISTORY = 2.0  # a net's crossing cost is multiplied by this each time it is ripped up
LAYERS = ("F.Cu", "B.Cu")


def mm(v):
    import pcbnew

    return pcbnew.ToMM(v)


# ---------------------------------------------------------------- geometry
def seg_dist(X, Y, a, b):
    """Distance from grid points to segment ab."""
    ax, ay = a
    bx, by = b
    dx, dy = bx - ax, by - ay
    L = dx * dx + dy * dy
    if L == 0:
        return np.hypot(X - ax, Y - ay)
    t = np.clip(((X - ax) * dx + (Y - ay) * dy) / L, 0.0, 1.0)
    return np.hypot(X - (ax + t * dx), Y - (ay + t * dy))


def poly_dist(X, Y, pts):
    """Distance from grid points to a polygon (0 inside)."""
    d = np.full(X.shape, np.inf)
    inside = np.zeros(X.shape, dtype=bool)
    n = len(pts)
    for i in range(n):
        a, b = pts[i], pts[(i + 1) % n]
        d = np.minimum(d, seg_dist(X, Y, a, b))
        (x1, y1), (x2, y2) = a, b
        if y1 != y2:
            cross = ((y1 > Y) != (y2 > Y)) & (X < (x2 - x1) * (Y - y1) / (y2 - y1) + x1)
            inside ^= cross
    d[inside] = 0.0
    return d


class Copper:
    """One piece of copper: pad polygon, or track/via capsule, on given layers."""

    def __init__(self, net, layers, poly=None, cap=None, hole=None, smd=False, item=None):
        self.net, self.layers, self.poly, self.cap = net, layers, poly, cap
        self.hole, self.smd, self.item = hole, smd, item
        pts = poly if poly is not None else [cap[0], cap[1]]
        r = 0 if poly is not None else cap[2]
        xs, ys = [p[0] for p in pts], [p[1] for p in pts]
        self.bbox = (min(xs) - r, min(ys) - r, max(xs) + r, max(ys) + r)

    def dist(self, X, Y):
        if self.poly is not None:
            return poly_dist(X, Y, self.poly)
        a, b, r = self.cap
        return seg_dist(X, Y, a, b) - r


def collect(board):
    import pcbnew

    items = []
    for fp in board.GetFootprints():
        for pad in fp.Pads():
            layers = tuple(L for L, lid in zip(LAYERS, (pcbnew.F_Cu, pcbnew.B_Cu)) if pad.IsOnLayer(lid))
            hole = None
            if pad.HasHole():
                ds = pad.GetDrillSize()
                hole = (mm(pad.GetPosition().x), mm(pad.GetPosition().y), mm(max(ds.x, ds.y)) / 2)
            lid = pcbnew.F_Cu if "F.Cu" in layers else pcbnew.B_Cu
            if not layers:  # NPTH: hole only
                items.append(Copper("", (), cap=((hole[0], hole[1]), (hole[0], hole[1]), 0.0), hole=hole))
                continue
            o = pad.GetEffectivePolygon(lid).Outline(0)
            poly = [(mm(o.CPoint(i).x), mm(o.CPoint(i).y)) for i in range(o.PointCount())]
            items.append(Copper(pad.GetNetname(), layers, poly=poly, hole=hole,
                                smd=not pad.HasHole(), item=pad))
    for t in board.GetTracks():
        if t.GetClass() == "PCB_VIA":
            p = (mm(t.GetPosition().x), mm(t.GetPosition().y))
            items.append(Copper(t.GetNetname(), LAYERS, cap=(p, p, mm(t.GetWidth(pcbnew.F_Cu)) / 2),
                                hole=(p[0], p[1], mm(t.GetDrillValue()) / 2), item=t))
        else:
            a = (mm(t.GetStart().x), mm(t.GetStart().y))
            b = (mm(t.GetEnd().x), mm(t.GetEnd().y))
            items.append(Copper(t.GetNetname(), (t.GetLayerName(),), cap=(a, b, mm(t.GetWidth()) / 2), item=t))
    return items


# ---------------------------------------------------------------- open connections
def item_key(item):
    """Identity of a board item. Pads of identical footprints share UUIDs,
    so a pad is named by its footprint reference and number instead."""
    if item.GetClass() == "PAD":
        return ("pad", item.GetParentFootprint().GetReference(), item.GetNumber())
    return ("item", item.m_Uuid.AsString())
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

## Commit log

2026-10-05 Add tscircuit RP2354A Solartron 7075 USB interface
    Opto-isolated (TLP2361) shift-register interface to the 70754 Parallel
    BCD Interface socket SKB: 5 x 74LV165A read the 36 DVM outputs, 2 x
    74LV595A + 2 x 74LVC07A drive the 13 commands open-drain. Vertical
    DD-50 plug on the bottom side, vertical USB-B on top.
    Claude-Session: https://claude.ai/code/session_01HFVXt44oTC7oWaEmmUfRaA
2026-10-05 Route and verify Solartron 7075 interface board, export outputs
    - Copper keepout along the isolation barrier so the autorouter cannot
    cross it; check-isolation script verifies the routed board
    - 0.2/0.45 mm vias (JLCPCB standard), crystal rotated for direct XIN/XOUT
    routes, placement fixes for courtyard DRC
    - Schematic grouped into sections with decoupling caps per rail and
    long wires replaced by net labels
    - npm build/check/export scripts; outputs/ holds Gerbers+BOM+CPL,
    schematic SVG/PDF, PCB views and netlist
    - Top-level README describing the benchmark layout
    Claude-Session: https://claude.ai/code/session_01HFVXt44oTC7oWaEmm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
2026-10-06 Vector schematic PDF and separated schematic sections
    tsci's schematic-pdf export embeds a 144 dpi bitmap on an A4 page, which
    is blurry. Add scripts/svg-to-pdf.mjs (headless Chromium print of the
    SVG with a viewBox added) producing an A1-width vector PDF, and use it in
    the export script.
    Move the isolation-barrier and isolated-supply schematic blocks right so
    their section titles no longer overlap the MCU section, and space out the
    SWD test point labels. PCB placement and routing are unchanged (same
    single same-net via/pad DRC note, no shorts, barrier check clean).
    Claude-Session: https://claude.ai/code/session_01HFVXt44oTC7oWaEmmUfR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
2026-10-06 Add atopile design: RP2354A USB interface for Solartron 7075
    USB interface board that plugs into the 50-way SKB socket of the
    Solartron 7075 Parallel BCD Interface Unit (service manual section 9).
    - RP2354A + USB-B (vertical, top face), TLV75901 3.3 V LDO
    - Opto-isolated DVM side: IB0505LS isolated 5 V supply, six TLP2361
    channels (SCK/MOSI/LATCH/OE_N out, MISO/DRDY back)
    - 5x 74HCT165 read SKB pins 1-36; 2x 74HCT595 drive SKB pins 38-50,
    2N7002 provides the contact-closure SAMPLE on pin 39
    - Vertical DD-50 plug (Amphenol DD50P364TXLF) on the bottom face,
    fixed by jackscrews; 78 x 60 mm board, components placed, GND /
    GND_ISO pours and barrier keep-out added (not yet routed)
    - Libra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
    [1.STEP, C0402_L1.0-W0.5-H0.5.step, C0603_L1.6-W0.8-H0.8.step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]
2026-10-06 Add schematic PDF export and name remaining nets
    - scripts/export_schematic.py: builds a hierarchical KiCad schematic
    from atopile's outputs (PCB netlist, BOM values, per-part symbols),
    one sheet per subsystem with a net label on every pin, plots it with
    kicad-cli and verifies the schematic netlist matches the atopile
    netlist net-for-net
    - schematic/: generated KiCad 10 schematic + solartron_7075_usb.pdf
    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
    [default.kicad_pcb, dvm.kicad_sch, isolation.kicad_sch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]
2026-10-06 README: complete the open-items list
    Add the screwlock thread check plus the other unverified assumptions:
    DD-50 mating orientation on the bottom face, connector/opto details
    inferred without datasheets, 595 high level vs the 7075 +5 V input
    max, assumed 7075 input pull-ups, IB0505LS input range vs VBUS, and
    firmware not yet written. Note that all other parts were in JLCPCB
    stock when checked.
    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
2026-10-06 Run ERC on the schematic; confirm Hi-Z command inputs are inactive
    Schematic export:
    - Assign real electrical pin types (datasheet-based for the ICs,
    passive otherwise); atopile's EasyEDA symbols type every pin
    input/unspecified, which gave 460 meaningless ERC violations
    - Add PWR_FLAGs on the four rails fed through passives (GND, +5V,
    +1V1, VREG_AVDD), write sym/fp library tables and a project file
    - Run KiCad ERC as part of the export: 0 errors, 0 warnings
    (negative test: dropping the +5V flag is reported as an error)
    Manual section 9, diag 9.2 (70754 board 2): every command input has a
    4.7k pull-up to +5V into TTL, contact SAMPLE a 2.2k pull-up, and pulse
    SAMPLE is AC-coupled. Hi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
    [dvm.kicad_sch, isolation.kicad_sch, mcu.kicad_sch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]
2026-10-06 Fix Gerber paste and rotated pads, add PCB prints and renders
    - scripts/prepare-fab.mjs: export Gerbers from a fixed copy of the routed
    board. tscircuit 0.0.2745 put no paste on pill/polygon pads (every SOIC,
    TLP2361 and the SOT-89 tab), pasted all through-holes and used 70 %
    apertures; the stencil is now 1:1 with a windowpane on the RP2354A pad.
    U2/U3 pads relied on Gerber %LR, which older CAM ignores (U3 pads would
    merge); they are now plain rectangles of the same outline.
    - scripts/pcb-prints.mjs: 7-sheet A4 vector print set (1:1 views, copper,
    assembly, stencil, drill drawing) and top/bottom renders, all drawn from
    gerbers.zip with tracespace.
    - Copper, mask, silk, outline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
2026-10-06 atopile: gerbers, 1:1 prints and 3D renders of the PCB
    - scripts/export_pcb.py: DRC with zone refill, gerbers + Excellon drill
    (zipped, named _UNROUTED_ while DRC reports unrouted connections),
    3-page 1:1 A4 prints with title block, and 3D renders, all from a
    temporary copy of the atopile layout
    - layouts/default/default.kicad_pro: JLCPCB 2-layer design rules
    - place_components.py: move the pre-routed TLV75901 block (parts,
    tracks, vias) rigidly; pours to the barrier edge; DC-DC and R10 moved
    clear of the board edge; zone polygons without uuid (KiCad 10)
    - check_layout.py: pad-to-pad check inside pre-routed library blocks
    - Fix EasyEDA 3D model offsets for IB0505LS (y), USB-B (z) a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
    [default.kicad_pcb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]
2026-10-07 Add SKiDL design for an isolated Solartron 7075 USB interface
    RP2354A-based interface for the 50-way SKB socket of the 7075's Parallel
    BCD Interface Unit (manual section 9), described in SKiDL and laid out
    for KiCad 10:
    - 5 x 74HCT165 read the 36 meter outputs, 2 x 74HC595 drive the 13
    command inputs; only SCLK/MOSI/LATCH//OE and MISO cross the barrier,
    each through a TLP2361 optocoupler
    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
    [bom.csv, bom_jlcpcb.csv, positions_kicad.csv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]
2026-10-07 Add verified single-page schematic, link board to it, split README issues
    - scripts/gen_schematic.py draws one A2 sheet from the SKiDL netlist
    (SKiDL's own generator mis-connects nets on this design) and checks it by
    re-exporting the netlist with kicad-cli: all 135 nets match in pins and
    names. KiCad ERC: 0 violations.
    - scripts/link_schematic.py gives footprints their symbol paths and BOM
    fields, renames nets as KiCad's Update PCB would, and adds no-connect
    nets, so DRC with --schematic-parity is clean (0/0/0). Copper unchanged.
    - build.sh runs both steps and exports the schematic PDF/PNG.
    - README: schematic section; tool issues separated from design caveats.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
    [solartron_7075_interface-B_Cu.gbl, solartron_7075_interface-B_Mask.gbs, solartron_7075_interface-B_Paste.gbp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]
2026-10-07 Add PCB prints and an independent Gerber preview
    - scripts/make_prints.py: pcb/print/pcb_prints.pdf, 7 A4 pages with title
    block (assembly top/bottom and all four copper layers at 2:1, plus a 1:1
    mirrored bottom view for checking the fit against the meter's socket),
    and pcb/print/gerber_preview.png, the fab Gerbers/drills rendered by gerbv.
    - link_schematic.py: board title block; idempotent re-runs, stable netclass
    pattern order.
    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
    [solartron_7075_interface-B_Cu.gbl, solartron_7075_interface-B_Mask.gbs, solartron_7075_interface-B_Paste.gbp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]
2026-10-07 Untangle DVM-side routing by pin swapping
    - New lib/dvmPinMap.ts holds which 74LV165A input, 74LV595A output,
    74LVC07A channel and RN element serves each SKB signal, and derives the
    firmware bit maps (MISO_BITS, COMMAND_BITS) from it.
    - 74LV165A inputs read the nearest SKB pins in planar order; the read chain
    now runs across the board (U10 -> U7 -> U9 -> U6 -> U8 -> MISO) instead of
    zig-zagging. Command-side assignment chosen by minimising ratsnest
    crossings; RN3/RN4 rotated 180 deg so signal pins face the buffers.
    - No part changed position. Routed result: 2780 mm of track (was 3520),
    248 vias (was 385), no DRC errors (was 1), no shorts, barrier clean.
    - README firmware tables u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
2026-10-07 Move command-side placement into lib/dvmPlacement.ts
    Positions and rotations of the 74LV595A/74LVC07A chips, pull-up arrays,
    R20 and R21 now come from one table, with each chip's decoupling cap
    following it. Pull-up array rotation moves there from dvmPinMap.ts. The
    board is unchanged (same pad positions, no DRC errors).
    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
2026-10-07 Move command-side parts to untangle routing further
    - 74LV595A, 74LVC07A, pull-up arrays, R20 and R21 re-placed and rotated
    (lib/dvmPlacement.ts), chosen together with a new 595 output / buffer
    channel / pull-up element assignment by simulated annealing on ratsnest
    crossings. Command-side crossings (incl. control and supply lines):
    158 -> 37. 74LV165A side unchanged.
    - Best of four routed candidates: 2643 mm of track (was 2780), 227 vias
    (was 248); below the D-sub 817 mm / 67 vias (was 915 / 91). No DRC
    errors, no shorts, isolation barrier clean, netlist check clean.
    - Command bit map changed: idle word now 0x67FE; README tables updated.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
2026-10-07 README: add review-feedback statistics table
    One row per tool. tscircuit: the routing clean-up (pin swapping, then
    moving command-side parts) took 1 h 35 min active, 48.9 M tokens (0.64 M
    excluding cache reads), 97 API calls, $16.38 at API prices.
    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
2026-10-07 atopile: pin-swap the shift registers to untangle the DD-50 routing
    - scripts/pin_swap.py: treats all 74HCT165 inputs, all 74HCT595 outputs
    and both chain orders as interchangeable, minimises ratsnest length +
    crossings (seeded simulated annealing) and regenerates the pin-map
    block in main.ato and the firmware bit-map tables in README.md
    - DVM-side ratsnest: 1544 mm / 839 crossings -> 860 mm / 154 crossings;
    165 chain now follows the physical row (124 mm -> 56 mm)
    - place_components.py: fixed register slots (the old centroid sort was
    not idempotent once the DD-50 sat on B.Cu and reversed the row)
    - schematic, ERC and fab outputs regenerated; no parts moved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
    [default.kicad_pcb, dvm.kicad_sch, isolation.kicad_sch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]
2026-10-07 README: rename Tools to Results, add schematic and PCB print links
    Claude-Session: https://claude.ai/code/session_01MqgJ99kvSuXHh7iSN2bN4c
2026-10-07 atopile README: Freerouting before/after comparison of the pin swap
    Claude-Session: https://claude.ai/code/session_01NqBEt2iCuw3VMJkgzgPtpr
2026-10-07 atopile: placement search script; faster pin-swap crossing count
    - scripts/optimise_placement.py: searches the IC row pattern/rotation,
    spots for the DRDY buffer and SAMPLE MOSFET and the opto order, scoring
    each candidate with a short pin-swap search (not applied yet)
    - place_components.py: DVM-side placement moved into a generated block
    (same positions as before)
    - pin_swap.py: crossing count only re-checks the changed nets (~10x
    faster, same results); optional fixed nets for the placement search
    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
    [optimise_placement.py, pin_swap.py, place_components.py]
2026-10-07 atopile: score the MOSFET drain net (SKB 39) in the placement search
    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
2026-10-07 atopile: move DVM-side parts for routing, then redo the pin swap
    - optimise_placement.py result: IC row (E->W) 165,595,165,595,165,165,165
    with the 165s turned 180 deg; DRDY buffer to the west end next to SKB 34;
    SAMPLE MOSFET + pull-down south of the DD-50 in line with SKB 39; opto
    order W->E DRDY, MISO, LATCH, MOSI, OE_N, SCK
    - pin_swap.py: control nets (SCK/LATCH/OE_N/DRDY, SKB 39 drain, MCU<->opto)
    now count for crossings; longer annealing and a chain-reversal move so
    all restarts converge
    - DVM ratsnest incl. control nets: 1206 mm / 297 crossings (pin swap only)
    -> 985 mm / 112 crossings (original: 1889 mm / 1000)
    - schematic, ERC, fab outputs, placement picture and README r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
    [default.kicad_pcb, dvm.kicad_sch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]
2026-10-08 atopile: 4-layer board with inner GND/supply planes and plane via drops
    - place_components.py: In1.Cu (GND | GND_ISO) and In2.Cu (+3V3 | +5V_ISO)
    plane layers, JLCPCB 7628 stack-up, barrier keep-out on all four layers,
    no outer pours
    - plane_vias.py: stub + via from every SMD pad on a plane net to its plane
    (148 vias, DRC clean), so the autorouter only routes signals
    - export_dsn.py / import_routing.py: Freerouting round trip that keeps the
    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
    [default.kicad_pcb]
2026-10-08 atopile: 0.2/0.15 mm default net class, Power class; lock tracks on SES import
    - default.kicad_pro: Default 0.2 mm track / 0.15 mm clearance so tracks can
    leave the RP2354A's 0.4 mm-pitch pins (0.25/0.2 left no room); Power
    class (VBUS, +5V) 0.4 mm
    - import_routing.py: lock the existing tracks before importing the
    session, which holds only Freerouting's additions
    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
    [import_routing.py]
2026-10-08 atopile: import Freerouting run (4 layers, via drops, 0.2/0.15 mm rules)
    Routed by Freerouting 2.1 with only the plane via drops and the LDO block
    locked; 2 connections (SCK, LATCH at the RP2354A) still open. Export and
    import now lock the same set (plane-net and grouped tracks), so a later
    run can rip up and finish the signal routing.
    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
    [default.kicad_pcb]
2026-10-08 atopile: keep plane via drops out of IC pins' escape zones
    plane_vias.py penalises via spots within 1.5 mm of another net's IC pin on
    its outward side. A decoupling cap's via under RP2354A pins 27/28 had
    blocked SCK and LATCH. Layout reset to the new via drops (unrouted) for
    the next Freerouting run.
    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
    [default.kicad_pcb]
2026-10-08 atopile: finish_routes.py, a small grid router for what Freerouting leaves
    A* on a 0.05 mm grid over F.Cu/B.Cu with through vias, net-class
    clearances plus a grid margin, a bend penalty for 45/90-degree tracks,
    and the barrier keep-out and board edge respected. Joins the closest
    pieces of each net that KiCad's connectivity still finds split.
    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
    [finish_routes.py]
2026-10-08 atopile: import Freerouting run 5; finish_routes.py clean-up and rip-up
    - layout: run 5 routing (patched Freerouting 2.1, escape-aware via
    drops); KiCad finds 8 nets still split, mostly at the RP2354A
    - finish_routes.py: removes dangling signal vias/tracks first, aligns
    its grid to absolute 0.05 mm (fine-pitch escapes), retries failed nets
    first, and rips up conflicting signal segments when a net still fails
    - import_routing.py: tracks_of() helper shared with finish_routes.py
    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
    [default.kicad_pcb]
2026-10-08 atopile: finish_routes.py negotiated rip-up; README note on 2-layer runs
    - rip-up routes with other nets' tracks as soft obstacles whose cost
    grows each time a net is ripped up, and tries every failed net per
    round (OE_N and MOSI had kept ripping each other up)
    - README: the 2-layer Freerouting counts leave ground out
    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
    [finish_routes.py]
2026-10-09 atopile: RP2354A decoupling caps 0.9 mm further out, for pin escape
    The caps sat 1.2 mm from the QFN pin tips, and with their via drops the
    channel could not hold the south-side signals (SCK, CLK, MISO, N_RESET
    kept displacing each other). Layout reset to the new placement and via
    drops, unrouted, for the next Freerouting run.
    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
    [default.kicad_pcb]
2026-10-09 atopile: import Freerouting run 6 (wider MCU escape channels)
    Freerouting 2.1 (patched) ended at 3 incomplete connections, no
    clearance violations; finish_routes.py is closing the rest.
    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
    [default.kicad_pcb]
2026-10-09 atopile: USB series resistors swapped and turned so DP/DM do not cross
    DP (pin 52) is west of DM (pin 51), but DP's resistor sat east of DM's,
    and both had their MCU-side pad facing away from the MCU, so the pair had
    to cross. Layout reset to the new placement and via drops, unrouted, for
    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
    [default.kicad_pcb]
2026-10-09 atopile: import Freerouting run 7 (after the USB resistor fix)
    Freerouting 2.1 (patched) ended at 2 incomplete connections, no
    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
    [default.kicad_pcb]
2026-10-09 atopile: plane_vias.py no-via area for the USB pair; strap fallback
    - NO_VIA_AREAS keeps via drops out of the DP/DM channel between RP2354A
    pins 51/52 and R7/R8 (two +3V3 drops there blocked the pair)
    - a pin with no free via spot is strapped to an adjacent same-net pin
    that has one (RP2354A pin 53 -> 54)
    Layout reset to the new via drops, unrouted, for the next run.
    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
    [default.kicad_pcb]
2026-10-09 atopile: import Freerouting run 8 (USB channel kept clear)
    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
    [default.kicad_pcb]
2026-10-09 atopile: Freerouting patch saves the final board; VREG_LX no-via area
    - freerouting-2.1.0-cli-output.patch (was -timeout.patch): also save the
    session after the router restores its best board; before, the .ses was
    a mid-pass snapshot (KiCad found up to 30 open connections where
    Freerouting reported 3)
    - plane_vias.py: no-via area on the VREG_LX path (RP2354A pin 48 to L1);
    a +3V3 drop there had blocked it
    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
    [default.kicad_pcb]
2026-10-09 atopile: board fully routed on 4 layers; fab outputs and README
    - layout: Freerouting run 10 (patched 2.1, plane via drops, no-via areas)
    plus finish_routes.py for the last 2 connections; KiCad DRC: 0 errors,
    0 unrouted (warnings: silkscreen, J1 footprint mismatch)
    - fab/: gerbers now include In1.Cu/In2.Cu, zip no longer _UNROUTED_,
    prints add the two plane layers, renders and DRC report regenerated
    - finish_routes.py: name pads by reference+number (pads of identical
    footprints share UUIDs, which merged split nets)
    - import_routing.py: --clear
    - README: "Planes and routing" section with the run-by-run table, routed
    board figure, updated outputs and open items; placement figure upda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
    [default.kicad_pcb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]
2026-10-10 Add opto-isolated RP2354A USB interface for the Solartron 7075, in Manta
    Board plugs onto the 50-way SKB socket of the 70754 Parallel BCD Interface
    Unit (service manual section 9). Five 74HCT165s read the meter's 36 outputs
    and two 74HCT595s drive its 13 command inputs, all on an isolated 5 V rail
    referenced to SKB pin 37; five TLP2361 optocouplers carry the shift clock,
    data, latch and output enable across the barrier. Parts come from manta's
    library where it has them and from LCSC otherwise.
    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
    [solartron7075-bom-lcsc.csv, solartron7075-bom.csv]
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2026-10-10 README: add SKiDL breakdown of the design session's statistics
    The Breakdown section now has a SKiDL table: active time, API calls, tokens
    and fitted API price split into schematic & research, PCB and other, from
    the first prompt to the conversation export. skidl/scripts/session_breakdown.py
    computes it from the session transcript; skidl/stats/breakdown_calls.csv
    lists each call's category; skidl/README.md notes the method and caveats.
    Claude-Session: https://claude.ai/code/session_01ERGgANCwEg9niX4WLDjBj2
    [breakdown_calls.csv]

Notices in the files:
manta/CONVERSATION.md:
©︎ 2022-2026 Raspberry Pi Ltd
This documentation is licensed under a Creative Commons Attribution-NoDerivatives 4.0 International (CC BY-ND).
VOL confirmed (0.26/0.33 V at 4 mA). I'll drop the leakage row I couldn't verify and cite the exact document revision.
